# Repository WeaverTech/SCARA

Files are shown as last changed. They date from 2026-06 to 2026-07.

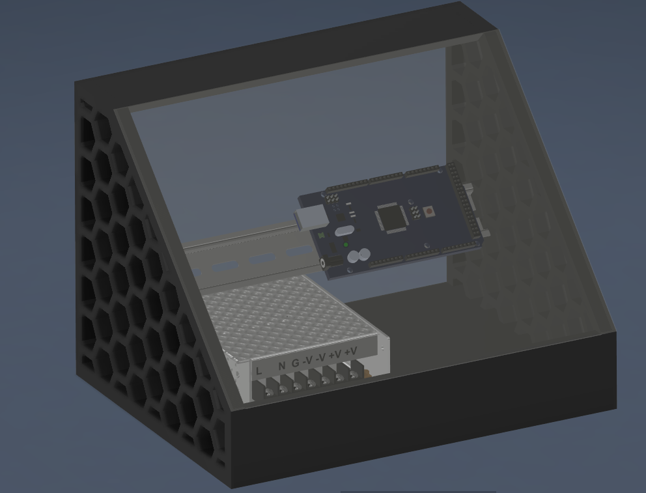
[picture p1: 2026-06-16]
cad/Zrzut ekranu 2026-06-10 202845.png

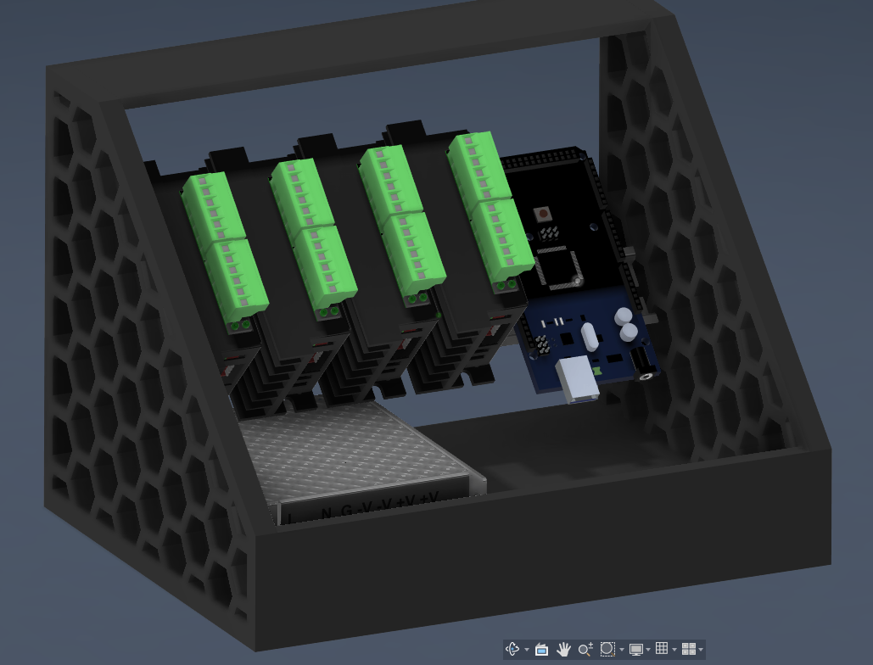
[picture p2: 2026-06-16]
cad/Zrzut ekranu 2026-06-10 203427.png

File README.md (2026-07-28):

# SCARA Robot

Repozytorium robota typu SCARA budowanego z profili aluminiowych 20x20 i
elementow drukowanych w 3D z PET-G. Docelowa konstrukcja to **dwuczlonowe
ramie** (bark + lokiec) z podnoszona osia Z oraz obrotowym efektorem koncowym.

> **Uwaga o prototypie fizycznym:** na etapie testow srodkowy przegub (lokiec)
> moze byc chwilowo pominiety, aby uniknac budowy drugiej przekladni
> cykloidalnej. W repozytorium kod i obliczenia traktuja jednak lokiec jako
> obecny (wersja docelowa). Do pracy bez fizycznego lokcia wystarczy ustawic
> `ELBOW_PRESENT = false` w [`src/main/main.ino`](src/main/main.ino).

## Architektura robota

Lancuch kinematyczny (4 osie / 4 silniki NEMA 17, 4 sterowniki TB6600):

- **Os Z** - ruch gora/dol realizowany na **pasku GT2** (prowadnice na walkach
  8 mm, wsporniki SHF8).
- **Bark (glowna os obrotowa)** - autorska, drukowana w 3D **przekladnia
  cykloidalna 20:1**.
- **Lokiec (srodkowy przegub)** - druga **przekladnia cykloidalna 20:1**
  (w prototypie opcjonalnie pomijana, patrz uwaga powyzej).
- **Efektor koncowy** - obrot narzedzia napedzany **paskiem zebatym** z silnika
  umieszczonego na ramieniu.

## Wymiary i dane kinematyczne

Wymiary zmierzone w CAD (od osi do osi):

| Parametr | Wartosc | Opis |
| --- | ---: | --- |
| Offset osi Z | 165 mm | Odleglosc kolumny Z od osi barku |
| Dlugosc ramienia L1 | 139.928 mm | Bark -> lokiec (zmierzone w CAD) |
| Dlugosc ramienia L2 | 140.000 mm | Lokiec -> efektor (zmierzone w CAD) |
| Maksymalny zasieg | 279.928 mm | L1 + L2 |
| Strefa martwa | 0.072 mm | \|L1 - L2\| |
| Strefa wykluczenia | R = 45 mm | Wokol kolumny Z (ochrona przed kolizja) |
| Przelozenie barku (J1) | 20:1 | Przekladnia cykloidalna |
| Przelozenie lokcia (J2) | 14:1 | Przekladnia cykloidalna |
| Mikrokrok | 1/16 | Ustawienie dla wszystkich sterownikow TB6600 |

### Przeliczniki krokow (mikrokrok 1/16, NEMA 17 = 200 krokow)

Pelny obrot silnika w mikrokrokach: `200 * 16 = 3200`.

```text
J1 (bark,  cykloidalna 20:1): (200 * 16 * 20) / 360 = 177.7778 krokow/stopien
J2 (lokiec, cykloidalna 14:1): (200 * 16 * 14) / 360 = 124.4444 krokow/stopien
Z  (sruba napedowa):           400 krokow/mm
```

Efektor (pasek zebaty z przelozeniem):

```text
steps/deg = (200 * 16 * przelozenie_paska) / 360
przelozenie_paska = zeby_kola_napedzanego / zeby_kola_silnika
```

> Przelozenie paska efektora (`TOOL_BELT_RATIO`) nalezy odczytac z modelu/BOM
> i uzupelnic w `src/main/config.h`.

## Elektronika

| Komponent | Konfiguracja |
| --- | --- |
| Mikrokontroler | Arduino Mega 2560, logika 5 V |
| Sterowniki | 4x TB6600 (wszystkie w uzyciu), sterowanie PUL/DIR/ENA |
| Silniki | 4x NEMA 17 (Z, bark, lokiec, efektor) |
| Zasilanie silnikow | Zasilacz przemyslowy 24 V, 8.3 A, 200 W |
| Zasilanie logiki | Osobny zasilacz 9 V do gniazda Arduino Mega |
| Krancowki | Opto/Hall: J1 -> pin 2, J2 -> pin 3, Z -> pin 18 (przerwania zewnetrzne) |

Masy zasilania logiki i sygnalow sterujacych TB6600 powinny byc wspolne
(mostkowane GND). Zasilanie silnikow (24 V) prowadzone jest oddzielnie do
sterownikow. Efektor nie ma krancowki (pozycja zerowa przyjmowana programowo).

## Modele CAD (`cad/`)

Pliki STEP wyeksportowane z Autodesk Fusion (AP214, jednostki: mm):

- `SCARA.step` - pelny montaz (rama, os Z, ramie, przekladnie, napedy).
- `ramie.step` - sam podzespol ramienia z przekladnia cykloidalna.

Wybrane elementy z listy materialowej (BOM):

- Rama: profile `2020 alu section`, `SCARA_FRAME_V2`.
- Os Z: walki 8 mm, wsporniki `SHF8`, wozek liniowy, pasek GT2.
- Przekladnia cykloidalna `Cycloidal Drive 160mm` (typ TRICY MH-P16): krzywki
  (`cam a-b`, `cam a-c`), pierscienie (`ring a/b/c`), 20 kolkow, waly
  wejsciowy/wyjsciowy, lozyska `NSK 6810ZZ` i `MH-P16`.
- Napedy: `NEMA17` + mocowania, plyty `Axis1`/`Axis2`.

## Struktura repozytorium

```text
.
+-- cad/                  # Modele 3D (STEP) i zrzuty konstrukcji
+-- docs/                 # Schematy, notatki montazowe i kalibracja
+-- host/                 # Klient Pythona (pyserial) dla firmware
+-- sim/                  # Kinematyka (URDF) i symulacja (PyBullet)
+-- webapp/               # Aplikacja webowa: GUI, punkty, programy, symulator
`-- src/
    `-- main/
        +-- config.h      # Geometria, przeliczniki, piny, limity
        `-- main.ino      # Firmware Arduino Mega (IK, homing, protokol)
```

## Aplikacja webowa (teach pendant)

W [`webapp/`](webapp/) znajduje sie lokalna aplikacja webowa w stylu RC+:
jog, pamiec punktow (Teach), edytor programow z interpolacja liniowa,
sterowanie predkoscia i gripperem (serwo SG90), wizualizacja 2D na zywo
oraz wbudowany symulator robota (praca bez sprzetu, port `sim`).
Uruchomienie: `cd webapp && pip install -r requirements.txt &&
uvicorn backend.main:app --port 8000`, GUI pod `http://localhost:8000`.

## Kinematyka i symulacja

W katalogu [`sim/`](sim/) znajduje sie model **URDF** robota, analityczna
kinematyka prosta i odwrotna (`kinematics.py`) oraz symulacja w **PyBullet**
(`simulate.py`). Przeliczniki katow na kroki silnikow sa spojne z firmware.
Model URDF jest standardowy, wiec da sie go uzyc takze w ROS 2 (RViz2, MoveIt 2,
Gazebo). Szczegoly: [`sim/README.md`](sim/README.md).

## Oprogramowanie

Firmware: [`src/main/main.ino`](src/main/main.ino) +
[`src/main/config.h`](src/main/config.h). Zawiera:

- pelna kinematyke odwrotna i prosta w plaszczyznie XY (dwa czlony L1/L2),
- wybor konfiguracji lokcia ("up"/"down") w komendzie ruchu,
- walidacje zasiegu, limitow stawow i strefy wykluczenia wokol kolumny Z,
- 3-fazowy homing (najazd -> odjazd -> wolny latch) na krancowkach z przerwaniami,
- monitoring krancowek w ruchu (przerwania zewnetrzne, ESTOP + wymagany re-home),
- liniowy protokol `OK`/`ERR`/`DONE` dla nadrzednego hosta w Pythonie,
- flage `ELBOW_PRESENT` do pracy bez fizycznego lokcia.

Host Python: [`host/scara_client.py`](host/scara_client.py) (pyserial) -
API `home()`, `move(x, y, z, tool)`, `jog()`, `solve_ik()`, `status()`.
Opis protokolu: [`host/README.md`](host/README.md).

### Wymagania

- Arduino IDE albo Arduino CLI.
- Plytka: **Arduino Mega 2560**.
- Biblioteka: **AccelStepper**.
- Host: Python 3 + **pyserial**.

### Przykladowe komendy szeregowe

Po wgraniu szkicu i otwarciu monitora portu szeregowego (`115200 baud`):

```text
PING
STATUS
HOME
MOVE X200 Y50 Z20 E1
IK X150 Y100
JOG J1 45
JOG Z 10
STOP
ESTOP
```

## Obudowa sterownika (Control Box)

Drukowana w 3D obudowa o strukturze plastra miodu (chlodzenie pasywne + miejsce
na wentylatory). Na dole zasilacz 24 V, nad nim zintegrowana szyna DIN dla
Arduino Mega, a 4 sterowniki TB6600 montowane pionowo obok siebie.

## Status projektu

Geometria (L1, L2, offset Z, zasieg) jest zmierzona w CAD i zweryfikowana.
Przed praca z pelnymi predkosciami nalezy:

1. Zweryfikowac kierunki ruchu wszystkich osi (`HOMING_DIR_*` w `config.h`).
2. Zmierzyc przelozenie paska efektora (`TOOL_BELT_RATIO`).
3. Zweryfikowac pozycje krancowek i wartosci `*_HOME_POS_*` w `config.h`.
4. Sprawdzic stany logiczne czujnikow (`LIMIT_ACTIVE_STATE`) i limity ruchu.

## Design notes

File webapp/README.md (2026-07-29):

# SCARA Web Control

Lokalna aplikacja webowa do sterowania robotem SCARA w stylu teach-pendant
(RC+): jog, pamiec punktow, budowanie i wykonywanie programow, wizualizacja 2D.

Polaczenie z robotem jest **przewodowe** - backend dziala na komputerze
podlaczonym kablem USB do Arduino Mega, a GUI otwierasz w przegladarce pod
`http://localhost:8000`. Wymaga firmware **SCARA-FW 2.2** (`../src/main/`).

## Uruchomienie

### Linux / macOS

```bash
cd webapp
python3 -m venv .venv && source .venv/bin/activate
pip install -r requirements.txt

uvicorn backend.main:app --host 127.0.0.1 --port 8000
```

### Windows (PowerShell)

```powershell
cd webapp
python -m venv .venv
.\.venv\Scripts\Activate.ps1
pip install -r requirements.txt

uvicorn backend.main:app --host 127.0.0.1 --port 8000
```

Nastepnie otworz [http://localhost:8000](http://localhost:8000), wybierz port
(np. `/dev/ttyACM0` lub `COM3`) i kliknij **Polacz**.

> **Praca bez sprzetu:** wybierz port `sim` - wbudowany symulator odpowiada
> identycznym protokolem co firmware i animuje ruch osi w czasie rzeczywistym.

## Polaczenie z Arduino (Windows)

Strona **nie** laczy sie z USB bezposrednio z przegladarki - robi to lokalny
backend (`pyserial`). Jesli wgranie przez Arduino IDE dziala, a **Polacz** na
stronie nie:

1. **Zamknij Serial Monitor** (i najlepiej samo Arduino IDE) - port COM jest
   wyłaczny; zajety port = blad `PORT_BUSY`.
2. Uruchom backend (`uvicorn …`) i otworz `http://127.0.0.1:8000` (nie plik
   `index.html` z dysku).
3. Kliknij **⟳**, wybierz **ten sam COM** co Tools → Port w IDE (nie `sim`).
4. Kliknij **Polacz**. W konsoli na dole powinny pojawic sie linie
   `READY SCARA-FW 2.2` oraz `OK PONG`.
5. Jesli widzisz `NO_RESPONSE`: wgraj ponownie `src/main/` (firmware 2.2),
   baud 115200, bez otwartego monitora szeregowego.

## Funkcje

- **Jog** osiowy (J1/J2/Z/TOOL, wzgledny - dziala tez przed homingiem)
  i kartezjanski (XY przez IK), wybor kroku, konfiguracja lokcia up/down.
- **Homing reczny** (praca bez krancowek): dojedz jogiem do pozycji
  krancowych (J1 = -125 st., J2 = -145 st., Z = 0) i kliknij "SET HOME" -
  biezaca pozycja staje sie pozycja odniesienia (komenda `SETHOME`,
  takze per-os). Uwaga: jog przed homingiem nie ma limitow programowych.
- **Predkosc globalna** 10-100% (suwak, komenda `SPEED`).
- **Gripper** (serwo SG90): otworz/zamknij (komenda `GRIP`).
- **Pamiec punktow**: Teach z biezacej pozycji, Go/Go-liniowy, punkty widoczne
  na wizualizacji; zapis w `data/points.json`.
- **Programy**: lista krokow (ruch joint/liniowy do punktu, Z, TOOL, gripper,
  czekaj) + liczba powtorzen; Run/Pauza/Wznow/Stop z podswietlaniem kroku;
  zapis w `data/programs.json`.
- **Interpolacja liniowa**: trasa TCP dzielona na segmenty 2 mm, cala trasa
  walidowana przed startem (zasieg, limity stawow, strefa kolizji kolumny).
- **Wizualizacja 2D** na zywo: ramie, obszar roboczy, strefa wykluczenia,
  punkty, slad TCP (polling STATUS ~10 Hz przez WebSocket).
- **Bezpieczenstwo**: STOP (rampa) i E-STOP (odciecie sterownikow, wymagany
  ponowny HOME) zawsze widoczne; blokada ruchow przed homingiem.
- **Konsola**: podglad surowej komunikacji + reczne komendy.

## Architektura

```
przegladarka (frontend/)  --HTTP/WS-->  FastAPI (backend/)  --USB-->  Arduino
```

| Modul | Rola |
| --- | --- |
| `backend/main.py` | REST API + WebSocket + serwowanie frontendu |
| `backend/robot_manager.py` | watki: reader / poller STATUS / runner programow |
| `backend/transport.py` | port szeregowy (pyserial) + symulator protokolu |
| `backend/interpolation.py` | segmentacja trasy liniowej + walidacja |
| `backend/kinematics_mm.py` | FK/IK w mm, zgodne 1:1 z firmware |
| `backend/storage.py` | punkty i programy w JSON (`data/`) |
| `frontend/` | GUI: HTML + vanilla JS + canvas |

## Testy

```bash
python3 -m pytest tests/ -q
```

Testy pokrywaja: FK/IK, interpolacje (segmentacja, odrzucanie tras
nieosiagalnych), storage, symulator protokolu oraz pelny cykl programu
(move -> grip -> move liniowy -> grip -> wait) na symulatorze.

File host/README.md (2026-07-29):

# Host Python dla SCARA

Klient `scara_client.py` komunikuje sie z firmware Arduino Mega
(`../src/main/main.ino`) przez port szeregowy (115200 baud).

## Instalacja

```bash
pip install -r requirements.txt
```

## Protokol

Kazda komenda dostaje jedna linie odpowiedzi `OK[ dane]` lub `ERR KOD opis`.
Po zakonczeniu ruchu kontroler wysyla asynchronicznie `DONE`.
Po resecie kontroler wysyla `READY SCARA-FW 2.0`.

| Komenda | Odpowiedz | Opis |
| --- | --- | --- |
| `PING` | `OK PONG` | test lacza |
| `VERSION` | `OK SCARA-FW 2.0` | wersja firmware |
| `STATUS` | `OK STATE=.. HOMED=.. X=.. Y=.. Z=.. J1=.. J2=.. TOOL=..` | pelny stan |
| `HOME [J1\|J2\|Z]` | `OK` / `ERR HOMING_FAIL ...` | homing na krancowkach (bez argumentu: Z, J1, J2) |
| `SETHOME [J1\|J2\|Z\|TOOL] [wart]` | `OK` | homing reczny: biezaca pozycja = krancowa z config.h (lub podana) |
| `JOGR J1\|J2\|Z\|TOOL <delta>` | `OK` + pozniej `DONE` | jog wzgledny; dziala tez przed homingiem (bez limitow!) |
| `MOVE X<mm> Y<mm> [Z<mm>] [T<deg>] [E0\|E1]` | `OK J1=.. J2=..` + pozniej `DONE` | ruch IK (E1 = lokiec "up") |
| `JOG J1\|J2\|Z\|TOOL <wartosc>` | `OK` + pozniej `DONE` | ruch pojedynczej osi |
| `IK X<mm> Y<mm> [E0\|E1]` | `OK J1=.. J2=.. REACHABLE=0\|1` | samo IK, bez ruchu |
| `SPEED <10-100>` | `OK` | globalny procent predkosci osi |
| `GRIP 0\|1` | `OK` | gripper (serwo SG90): 0 = otwarty, 1 = zamkniety |
| `STOP` | `OK` | stop z rampa |
| `ESTOP` | `OK` | stop natychmiastowy + DISABLE (wymaga HOME) |
| `ENABLE` / `DISABLE` | `OK` | sterowniki TB6600 |

Kody bledow: `BAD_CMD`, `NOT_HOMED`, `OUT_OF_REACH`, `EXCLUSION_ZONE`,
`JOINT_LIMIT`, `BUSY`, `LIMIT_HIT`, `HOMING_FAIL`, `AXIS_DISABLED`.

## Przyklad

```python
from scara_client import ScaraClient

with ScaraClient("/dev/ttyACM0") as robot:
    robot.home()                              # Z -> J1 -> J2
    robot.move(x=200.0, y=50.0, z=20.0)       # IK + ruch, czeka na DONE
    print(robot.status())
    print(robot.solve_ik(150.0, 100.0))       # samo IK w firmware
```

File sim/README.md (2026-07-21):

# Kinematyka i symulacja SCARA

Modul opisuje pelna kinematyke robota (model URDF), analityczna kinematyke
prosta/odwrotna oraz symulacje w PyBullet. Wszystko jest spojne ze stalymi
napedu z firmware ([`../src/main/main.ino`](../src/main/main.ino)).

## Zawartosc

| Plik | Opis |
| --- | --- |
| `scara.urdf` | Model URDF (lancuch kinematyczny, limity, geometria). |
| `kinematics.py` | Analityczna FK/IK + mapowanie katow na kroki silnikow. |
| `simulate.py` | Symulacja/wizualizacja w PyBullet (GUI lub headless). |
| `test_kinematics.py` | Testy FK/IK (round-trip, limity, kroki). |
| `requirements.txt` | Zaleznosci Pythona. |

## Model kinematyczny

SCARA z czterema osiami (wszystkie osie obrotowe sa pionowe, +Z):

```
world
  └─(fixed)        base_column        # pionowa wieza z profili 2020
      └─(Z, prismatic)  z_carriage    # podnoszenie na pasku GT2
          └─(shoulder, revolute) link1   # bark,  cykloidalna 20:1
              └─(elbow, revolute)  link2  # lokiec, cykloidalna 20:1
                  └─(tool, revolute) tool_link  # efektor (pasek)
                      └─(fixed) tool_tip         # punkt TCP
```

Parametry (zmierzone w CAD):

| Symbol | Wartosc | Opis |
| --- | ---: | --- |
| `z_offset` | 0.165 m | Kolumna -> os barku |
| `L1` | 0.139928 m | Bark -> lokiec |
| `L2` | 0.140000 m | Lokiec -> efektor |
| zakres Z | 0–0.15 m | Skok osi Z |
| strefa wykluczenia | R = 0.045 m | Wokol kolumny Z |

## Kinematyka prosta (FK)

Pozycja TCP w ukladzie osi barku:

```
x   = L1·cos(θ1) + L2·cos(θ1+θ2)
y   = L1·sin(θ1) + L2·sin(θ1+θ2)
z   = z_carriage                      (oś prismatic, niezależna)
φ   = θ1 + θ2 + θ_tool                (absolutna orientacja narzędzia)
```

## Kinematyka odwrotna (IK)

Dla zadanego (x, y, z, φ):

```
r²       = x² + y²
cos(θ2)  = (r² − L1² − L2²) / (2·L1·L2)
θ2       = ± acos(cos θ2)             (elbow "up" / "down")
θ1       = atan2(y, x) − atan2(L2·sin θ2, L1 + L2·cos θ2)
θ_tool   = φ − (θ1 + θ2)
z        = z (bezpośrednio)
```

Zwraca `None`, gdy punkt jest poza zasiegiem `|L1−L2| ≤ r ≤ L1+L2`.

## Mapowanie na kroki silnikow (spojne z firmware)

```
J1 bark   (cykloidalna 20:1): (200·16·20)/360 = 177.7778 kroków/°
J2 lokiec (cykloidalna 14:1): (200·16·14)/360 = 124.4444 kroków/°
oś Z (śruba napędowa):        400 kroków/mm
efektor (pasek):              (200·16·ratio)/360
```

## Uruchomienie

```bash
cd sim
python3 -m venv .venv && source .venv/bin/activate   # lub virtualenv
pip install -r requirements.txt

# Testy kinematyki
pytest -q

# Demo FK/IK w konsoli
python kinematics.py

# Symulacja bez okna (walidacja URDF + przejazd trajektorii)
python simulate.py --headless --demo

# Symulacja z oknem (wymaga srodowiska graficznego)
python simulate.py --demo
```

> Uwaga: `pybullet` kompiluje sie ze zrodel — na Linuksie wymaga naglowkow
> `python3-dev` oraz kompilatora `g++`/`build-essential`.

## Wykorzystanie w ROS 2 (opcjonalnie)

`scara.urdf` jest standardowym URDF, wiec dziala te z ekosystemem ROS 2:

- wizualizacja: `ros2 launch` + `robot_state_publisher` + RViz2,
- planowanie ruchu: MoveIt 2 (setup assistant wczyta URDF),
- symulacja fizyki: Gazebo (po dodaniu tagow `<gazebo>`).

## Dodanie realnych siatek (mesh) z CAD

Obecnie linki maja geometrie prymitywna (boxy/cylindry) dopasowana wymiarami.
Aby uzyc realnych ksztaltow:

1. W CAD wyeksportuj kazdy czlon do osobnego pliku **STL** (w mm).
2. Umiesc je w `sim/meshes/`.
3. W `scara.urdf` zamien `<geometry><box .../></geometry>` na
   `<geometry><mesh filename="meshes/link1.stl" scale="0.001 0.001 0.001"/></geometry>`
   (skala 0.001, bo URDF jest w metrach, a STL w mm).

## Status / TODO

- [x] Zmierzone realne L1 = 139.928 mm, L2 = 140.000 mm (CAD).
- [ ] Doprecyzowac limity stawow (z renderu widoczne adnotacje 60°/15°/25°).
- [ ] Dodac siatki STL dla lepszej wizualizacji i kolizji.
- [ ] (Opcjonalnie) pakiet ROS 2 + MoveIt 2.

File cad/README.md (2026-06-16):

# CAD

Modele 3D i materialy zrodlowe robota SCARA.

## Pliki w repozytorium

- `SCARA.step` - pelny montaz (rama 2020, os Z, ramie, dwie przekladnie
  cykloidalne, napedy NEMA 17). Eksport z Autodesk Fusion, AP214, jednostki mm.
- `ramie.step` - sam podzespol ramienia z przekladnia cykloidalna.
- `Zrzut ekranu *.png/.jpg` - rendery konstrukcji (cala maszyna, ramie,
  control box).

## Wybrana lista materialowa (BOM)

- **Rama:** profile `2020 alu section`, `SCARA_FRAME_V2`.
- **Os Z:** walki liniowe 8 mm, wsporniki `SHF8`, wozek liniowy
  (`8mm Mil Araba`), nakretka blokujaca, pasek GT2.
- **Przekladnia cykloidalna** `Cycloidal Drive 160mm` (TRICY MH-P16):
  krzywki `cam a-b` / `cam a-c`, pierscienie `ring a/b/c`, 20 kolkow (`pin`),
  waly `input-shaft` / `output shaft`, lozyska `NSK 6810ZZ` i `MH-P16 Bearing`,
  obudowa `housing-top` / `housing-bottom`.
- **Napedy:** `NEMA17 Model` + `Nema 17 mount` + `Gearbox Mount`,
  plyty `Axis1_Plate_*`, `Axis2_Plate_*`, dystanse.
- **Lacznik:** sruby `91292A352`, standoffy.

## Sugerowany podzial przy rozbudowie

- `printed-parts/` - elementy drukowane w 3D z PET-G,
- `control-box/` - obudowa elektroniki i mocowania sterownikow,
- `gearbox/` - przekladnia cykloidalna (bark i lokiec),
- `exports/` - pliki STL/STEP gotowe do druku lub obrobki.

> Pliki STEP sa duze (kilkanascie MB). Przy dalszym przyroscie ciezkich modeli
> warto rozwazyc Git LFS.

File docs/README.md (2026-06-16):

# Dokumentacja

Ten katalog jest przeznaczony na dokumentacje techniczna robota SCARA.

Proponowana zawartosc:

- schemat polaczen Arduino Mega 2560 ze sterownikami TB6600 (4 osie),
- schemat zasilania 24 V dla silnikow i 9 V dla logiki,
- notatki z kalibracji osi Z (pasek GT2) i efektora,
- opis procedury homingu z czujnikami optycznymi (Z, bark, lokiec),
- zdjecia montazu i rewizje mechaniczne.

## Mapa pinow (Arduino Mega 2560 -> TB6600)

| Os | Silnik / naped | STEP (PUL) | DIR | ENA | Krancowka |
| --- | --- | ---: | ---: | ---: | ---: |
| Z | NEMA 17 / pasek GT2 | 22 | 23 | 24 | 40 |
| Bark (SHOULDER) | NEMA 17 / cykloidalna 20:1 | 26 | 27 | 28 | 41 |
| Lokiec (ELBOW) | NEMA 17 / cykloidalna 20:1 | 30 | 31 | 32 | 42 |
| Efektor (TOOL) | NEMA 17 / pasek zebaty | 34 | 35 | 36 | - |

Efektor nie ma krancowki - pozycja zerowa przyjmowana programowo.

## Przeliczniki krokow

Mikrokrok 1/16, NEMA 17 = 200 krokow -> `3200` mikrokrokow na obrot silnika.

| Os | Wzor | Wynik |
| --- | --- | --- |
| Bark | `(200*16*20)/360` | 177.7778 krokow/stopien |
| Lokiec | `(200*16*20)/360` | 177.7778 krokow/stopien |
| Z (GT2) | `3200 / (zeby_kola * 2 mm)` | np. 20T -> 80 krokow/mm |
| Efektor | `(200*16*przelozenie)/360` | zalezne od kol pasowych |

## Dane do uzupelnienia podczas uruchomienia

| Parametr | Stala w kodzie | Wartosc |
| --- | --- | --- |
| Zeby kola pasowego osi Z | `Z_PULLEY_TEETH` | TODO |
| Kroki osi Z na 1 mm | `Z_STEPS_PER_MM` | TODO (wyliczane) |
| Przelozenie paska efektora | `TOOL_BELT_RATIO` | TODO |
| Kroki efektora na 1 stopien | `TOOL_STEPS_PER_DEGREE` | TODO (wyliczane) |
| Dlugosc czlonu L1 (bark->lokiec) | `ARM1_LENGTH_MM` | TODO (pomiar z CAD) |
| Dlugosc czlonu L2 (lokiec->efektor) | `ARM2_LENGTH_MM` | TODO (pomiar z CAD) |
| Stan aktywny krancowki Z | - | TODO |
| Stan aktywny krancowki barku | - | TODO |
| Stan aktywny krancowki lokcia | - | TODO |

## Tryb prototypu bez lokcia

Druga przekladnia cykloidalna moze byc dobudowana pozniej. Do testow bez niej
nalezy w `src/main/main.ino` ustawic:

```cpp
constexpr bool ELBOW_PRESENT = false;
```

Sterownik pominie wtedy zalaczanie, homing i ruchy osi lokcia, zachowujac pelna
obsluge osi Z, barku i efektora.

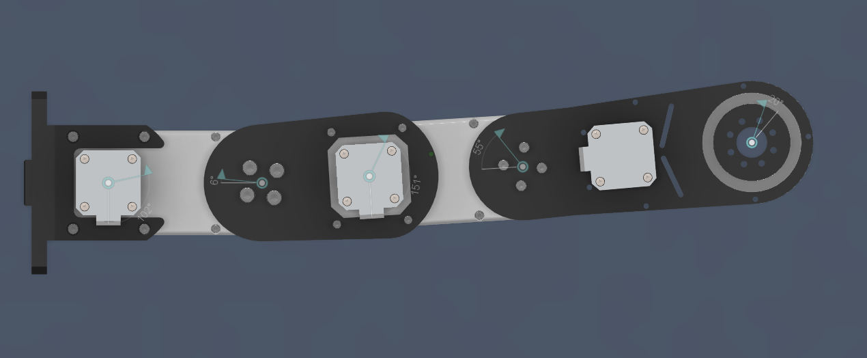
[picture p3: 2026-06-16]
cad/Zrzut ekranu 2026-06-16 174000.png

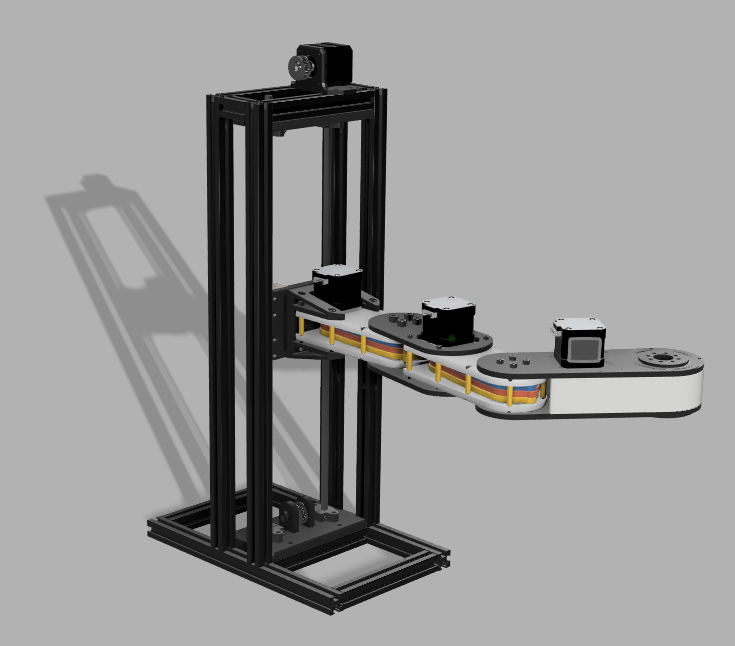
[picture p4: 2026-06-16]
cad/Zrzut ekranu 2026-06-09 221726.png

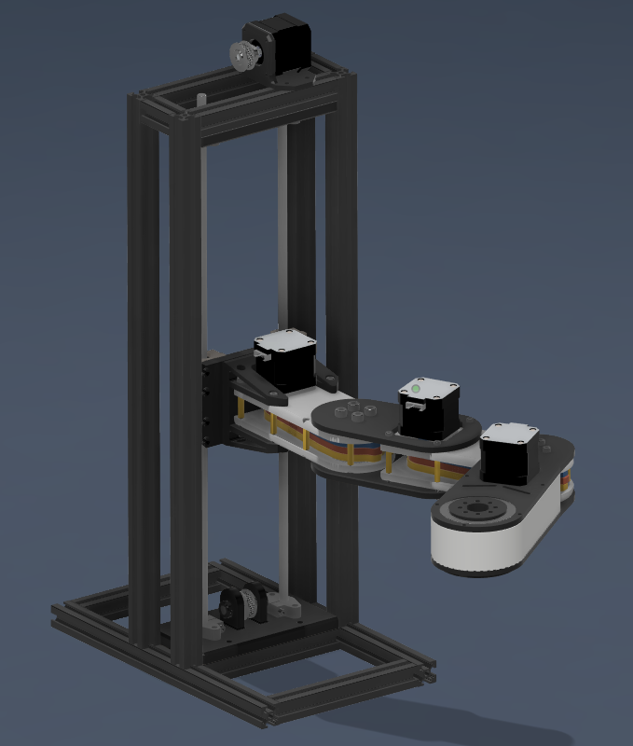
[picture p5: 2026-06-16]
cad/Zrzut ekranu 2026-06-16 173825.png

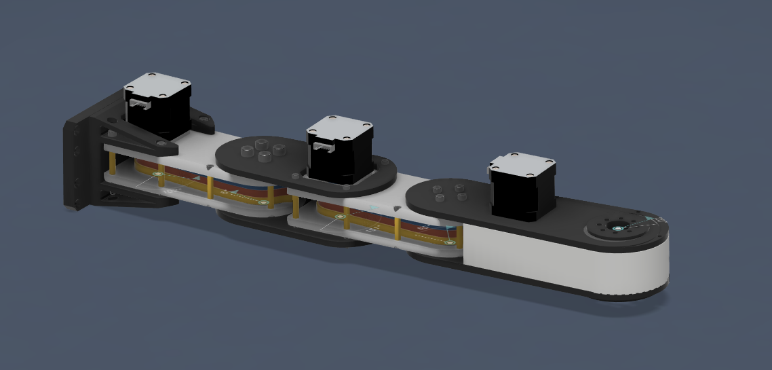
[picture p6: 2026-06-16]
cad/Zrzut ekranu 2026-06-10 000410.png

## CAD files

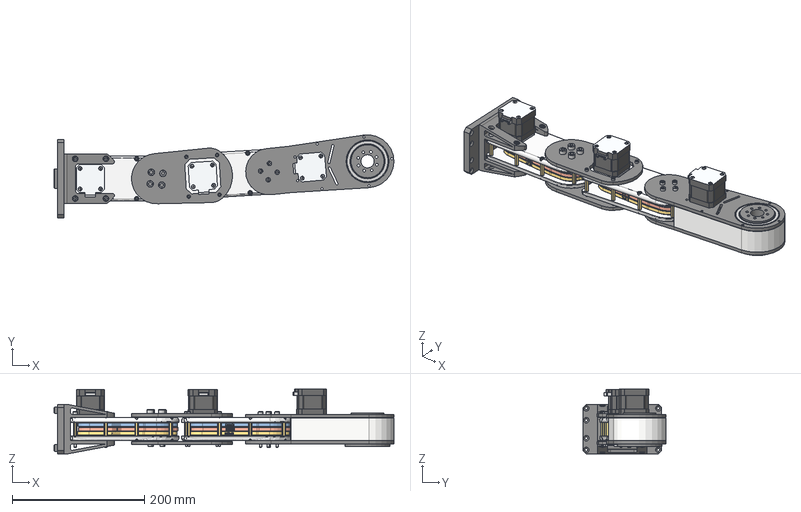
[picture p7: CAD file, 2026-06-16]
cad/ramie.step
513.8 x 125.6 x 98.2 mm
Z axis Plate v2
Komponent33 x 4
MH-P16 Bearing x 4
input bearing x 4
housing-bottom x 2
housing-top x 2
output shaft x 2
output shaft 2 x 2
pin x 40
cam a-b x 2
ring b x 2
cam bearing x 6
ring c x 2
cam a-c x 2
ring a x 2
standoff x 8
standoff_1 x 8
Dystans_Osi x 2
NEMA17 Model x 3
BSHCS ASME B18.3.1M - M3x0.5 x 30 Stal klasy 2 Płaszczyzna x 8
ISO 4032 - M3 Stal 6 Płaszczyzna x 16
BSHCS ASME B18.3.1M - M3x0.5 x 12 Stal klasy 2 Płaszczyzna x 8
BSHCS ASME B18.3.1M - M3x0.5 x 32 Stal klasy 2 Płaszczyzna x 8
BSHCS ASME B18.3.1M - M6x1 x 50 Stal klasy 2 Płaszczyzna x 4
Axis1_Plate_Top
Axis1_Plate_Btm
BSHCS ASME B18.3.1M - M4x0.7 x 50 Stal klasy 2 Płaszczyzna x 8
BSHCS ASME B18.3.1M - M3x0.5 x 50 Stal klasy 2 Płaszczyzna x 4
Gearbox Mount
Axis1_Spacer
Axis1_Spacer(Odbicie)
6810ZZ Outer ring x 2
6810ZZ Shield1 x 2
6810ZZ Inner ring x 2
6810ZZ Ball x 26
6810ZZ Shield2 x 2
Plate_Bottom
GT2 36T id 6.35mm bw 7mm
EndShaft

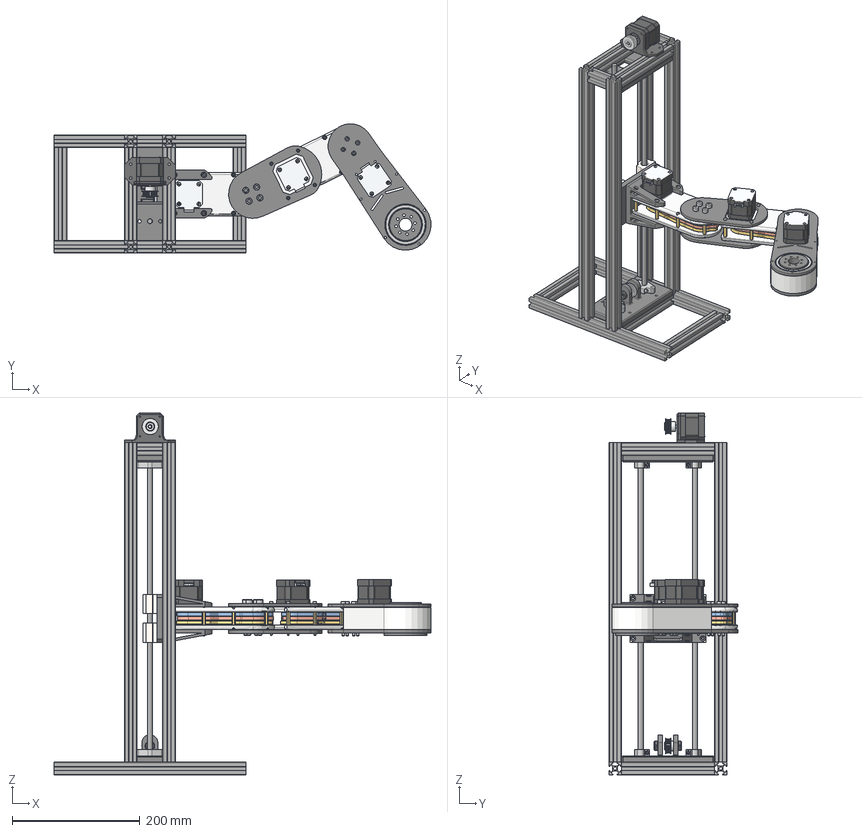
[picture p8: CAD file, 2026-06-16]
cad/SCARA.step
589.6 x 202.5 x 566.2 mm
Konfiguracja 1 v3
Konfiguracja 1 v3 (3)
Konfiguracja 1
Konfiguracja 1 v3 (1)
Konfiguracja 1 v3 (2)
2020 alu section x 2
Konfiguracja 1 v3 (4)
2020 alu section_1 x 6
91292A352
Shaft_Plate
GT2 36T id 6.35mm bw 7mm x 3
8mm Mil Araba - Step x 2
91292A352(Odbicie)
Długość x 2
91292A352(Odbicie) (1)
91292A352(Odbicie)(Odbicie)
NEMA17 Model x 4
Shaft_Plate_Top
8mm Mil Araba - Step_1 x 2
Nema 17 mount
8mm shaft locking nut x 2
Z axis Plate v2
Komponent33 x 4
MH-P16 Bearing x 4
input bearing x 4
housing-bottom x 2
housing-top x 2
output shaft x 2
output shaft 2 x 2
pin x 40
cam a-b x 2
ring b x 2
cam bearing x 6
ring c x 2
cam a-c x 2
ring a x 2
standoff x 8
standoff_1 x 8
Dystans_Osi x 2
BSHCS ASME B18.3.1M - M3x0.5 x 30 Stal klasy 2 Płaszczyzna x 8
ISO 4032 - M3 Stal 6 Płaszczyzna x 16
BSHCS ASME B18.3.1M - M3x0.5 x 12 Stal klasy 2 Płaszczyzna x 8
BSHCS ASME B18.3.1M - M3x0.5 x 32 Stal klasy 2 Płaszczyzna x 8
BSHCS ASME B18.3.1M - M6x1 x 50 Stal klasy 2 Płaszczyzna x 4
Axis1_Plate_Top
Axis1_Plate_Btm
BSHCS ASME B18.3.1M - M4x0.7 x 50 Stal klasy 2 Płaszczyzna x 8
BSHCS ASME B18.3.1M - M3x0.5 x 50 Stal klasy 2 Płaszczyzna x 4
Gearbox Mount
Axis1_Spacer
Axis1_Spacer(Odbicie)
6810ZZ Outer ring x 2
6810ZZ Shield1 x 2
6810ZZ Inner ring x 2
6810ZZ Ball x 26
6810ZZ Shield2 x 2
Plate_Bottom
EndShaft

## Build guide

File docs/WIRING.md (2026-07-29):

# SCARA - kompletny schemat okablowania

Okablowanie dla firmware **SCARA-FW 2.2** (`src/main/config.h`).
Kontroler: Arduino Mega 2560, 4x sterownik TB6600, 4x NEMA 17,
serwo SG90 (gripper), opcjonalnie 3 krancowki optyczne.

## Schemat ogolny

```
                 +--------------------+
 PC (USB) -------|  Arduino Mega 2560 |
                 |  (logika 5 V)      |
 9 V PSU -------(barrel jack)         |
                 +---+----+----+----+-+
                     |    |    |    |         sygnaly PUL/DIR/ENA (5 V)
                +----+    |    |    +-------------------+
                |         |    |                        |
           +----v---+ +---v----+ +--------+        +---v----+
           | TB6600 | | TB6600 | | TB6600 |        | TB6600 |
           |   Z    | |   J1   | |   J2   |        |  TOOL  |
           +--+--+--+ +--+--+--+ +--+--+--+        +--+--+--+
              |  |       |  |       |  |              |  |
            24V  M     24V  M     24V  M            24V  M
              |  |       |  |       |  |              |  |
    24 V PSU -+--|-------+--|-------+--|--------------+  |
    (8.3 A)      |          |          |                 |
              NEMA17     NEMA17     NEMA17            NEMA17
              (os Z)     (bark)     (lokiec)          (efektor)
```

Trzy niezalezne obwody zasilania:

| Obwod | Zrodlo | Zasila |
| --- | --- | --- |
| Silniki | 24 V / 8.3 A (200 W) | Zaciski VCC/GND kazdego TB6600 |
| Logika | 9 V (barrel jack) | Arduino Mega |
| Serwo | 5 V (UBEC/BEC min. 1 A) | SG90 grippera (masa wspolna z Arduino!) |

> TB6600 maja wejscia optoizolowane, wiec masa 24 V **nie musi** byc laczona
> z masa Arduino. Masa serwa SG90 i ewentualnych krancowek **musi** byc
> wspolna z GND Arduino.

## 1. Sterowniki TB6600 -> Arduino Mega

Podlaczenie **wspolna katoda**: wszystkie wejscia `PUL-`, `DIR-`, `ENA-`
kazdego sterownika do **GND Arduino**. Wejscia `+` do pinow:

| Sterownik (os) | PUL+ | DIR+ | ENA+ | PUL-/DIR-/ENA- |
| --- | ---: | ---: | ---: | --- |
| Z (sruba) | 22 | 23 | 24 | GND Arduino |
| J1 (bark, 20:1) | 26 | 27 | 28 | GND Arduino |
| J2 (lokiec, 14:1) | 30 | 31 | 32 | GND Arduino |
| TOOL (efektor) | 34 | 35 | 36 | GND Arduino |

Logika ENA w firmware: pin **LOW = sterownik zalaczony** (ENABLE),
pin HIGH = odlaczony (DISABLE/ESTOP). Przy wspolnej katodzie dziala to
"z pudelka" - nic nie trzeba zmieniac.

## 2. Zasilanie i silniki -> TB6600

Kazdy TB6600:

| Zacisk | Podlaczenie |
| --- | --- |
| VCC | +24 V z zasilacza |
| GND | -V (masa) zasilacza 24 V |
| A+, A- | pierwsza cewka silnika |
| B+, B- | druga cewka silnika |

Pary cewek NEMA 17 znajdziesz multimetrem (para = ok. 1-3 om) albo
zwierajac dwa przewody - jesli walem kreci sie ciezko, to jest para.
Zamiana A+ z A- odwraca kierunek obrotow (alternatywa: `HOMING_DIR_*`
w `config.h`).

**Przekroje:** 24 V do sterownikow oraz silniki min. 0.5 mm2 (AWG20).
Sygnaly logiczne moga byc cienkie (0.25 mm2), najlepiej skrecane parami.

## 3. Przelaczniki DIP na TB6600 (wszystkie 4 sztuki tak samo)

- **Mikrokrok: 1/16 = 3200 imp/obr** - ustaw S1-S3 wg tabelki nadrukowanej
  na sterowniku w pozycji "3200 Pulse/rev" (tabelki roznia sie miedzy
  wersjami TB6600, dlatego kieruj sie nadrukiem, nie internetem).
- **Prad: ok. 1.5 A** (S4-S6 wg nadruku) - typowa wartosc dla NEMA 17;
  sprawdz prad znamionowy swoich silnikow i nie przekraczaj go.

Firmware zaklada 3200 krokow/obrot - inne ustawienie mikrokroku rozjedzie
wszystkie przeliczniki!

## 4. Krancowki (opcjonalne - bez nich uzywaj homingu recznego SETHOME)

Piny z przerwaniami zewnetrznymi, wejscia z `INPUT_PULLUP`,
stan aktywny **LOW**:

| Os | Pin Arduino | Czujnik optyczny (3 piny) | Mikrostyk (2 piny) |
| --- | ---: | --- | --- |
| J1 | 2 | VCC->5V, GND->GND, OUT->pin 2 | COM->GND, NO->pin 2 |
| J2 | 3 | VCC->5V, GND->GND, OUT->pin 3 | COM->GND, NO->pin 3 |
| Z | 18 | VCC->5V, GND->GND, OUT->pin 18 | COM->GND, NO->pin 18 |

Niepodlaczone piny sa bezpieczne (pullup trzyma stan HIGH = nieaktywny),
wiec robot dziala bez krancowek - homing wykonuj komenda `SETHOME`
(sekcja "Homing reczny" w aplikacji webowej).

> Jesli czujnik daje stan HIGH przy zadzialaniu, zmien
> `LIMIT_ACTIVE_STATE` w `config.h` na `HIGH`.

## 5. Gripper - serwo SG90

| Przewod SG90 | Podlaczenie |
| --- | --- |
| Pomaranczowy (sygnal) | pin **44** Arduino |
| Czerwony (+) | +5 V z **osobnego** zrodla 5 V (UBEC/BEC >= 1 A) |
| Brazowy (GND) | GND zrodla 5 V **oraz** GND Arduino (wspolna masa!) |

Nie zasilaj serwa z pinu 5V Arduino - SG90 przy zablokowaniu potrafi
pobrac >0.5 A i zresetuje plytke. Katy otwarcia/zamkniecia: `GRIPPER_OPEN_DEG`
/ `GRIPPER_CLOSED_DEG` w `config.h` (domyslnie 20 / 110 stopni).

## 6. Kolejnosc uruchomienia i test

1. Sprawdz DIP-y (3200 imp/obr, prad) **przed** podaniem 24 V.
2. Podlacz USB (bez 24 V) - wgraj firmware, w monitorze portu (115200)
   sprawdz `PING` -> `OK PONG`.
3. Podaj 24 V, komenda `ENABLE` - silniki powinny "zesztywniec".
4. `SETHOME`, potem `JOGR J1 5` - os ma sie ruszyc o 5 stopni. Sprawdz
   kierunki wszystkich osi (`JOGR J2/Z/TOOL ...`); odwrocone kierunki
   napraw zamiana A+/A- albo znakiem `HOMING_DIR_*`.
5. `GRIP 1` / `GRIP 0` - test grippera.
6. Dalej pracuj z aplikacji webowej (`webapp/`), najpierw na 10-20%
   predkosci.

## Checklist bezpieczenstwa

- [ ] Wspolna masa: Arduino GND <-> PUL-/DIR-/ENA- wszystkich TB6600.
- [ ] Wspolna masa: Arduino GND <-> GND zasilania serwa.
- [ ] Masa 24 V NIE laczona z logika (optoizolacja TB6600).
- [ ] DIP: 3200 imp/obr i prad <= znamionowego silnika (x4).
- [ ] Nigdy nie rozlaczaj przewodow silnika przy wlaczonym 24 V
      (grozi uszkodzeniem sterownika).
- [ ] Pierwsze ruchy: mala predkosc, reka na E-STOP w GUI.

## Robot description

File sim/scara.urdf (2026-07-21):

<?xml version="1.0"?>
<!--
  SCARA robot - model kinematyczny (URDF).

  Lancuch kinematyczny (zgodny z firmware src/main/main.ino):
    world
      +- (fixed)      base_column        # pionowa wieza z profili 2020
            +- (Z, prismatic)  z_carriage   # podnoszenie na pasku GT2
                  +- (shoulder, revolute)  link1   # bark, cykloidalna 20:1
                        +- (elbow, revolute)  link2  # lokiec, cykloidalna 20:1
                              +- (tool, revolute)  tool_link  # efektor (pasek)
                                    +- (fixed)  tool_tip       # punkt TCP

  Jednostki URDF: metry, radiany.
  Wszystkie osie obrotowe sa pionowe (+Z) - typowa geometria SCARA.

  Wymiary (z briefu / CAD; TODO: dlugosci czlonow potwierdzic pomiarem):
    Z offset (kolumna -> os barku)      = 0.165 m
    L1 (os barku  -> os lokcia)         = 0.139928 m  (zmierzone w CAD)
    L2 (os lokcia -> os efektora)       = 0.140000 m  (zmierzone w CAD)
    Skok osi Z (zakres prismatic)       = 0.150 m
-->
<robot name="scara">

  <!-- ===================== Materialy ===================== -->
  <material name="alu">   <color rgba="0.25 0.25 0.27 1.0"/></material>
  <material name="carriage"><color rgba="0.85 0.85 0.88 1.0"/></material>
  <material name="arm">   <color rgba="0.90 0.90 0.92 1.0"/></material>
  <material name="forearm"><color rgba="0.75 0.78 0.82 1.0"/></material>
  <material name="tool">  <color rgba="0.20 0.55 0.90 1.0"/></material>

  <!-- ===================== Baza / kolumna ===================== -->
  <link name="world"/>

  <link name="base_column">
    <visual>
      <origin xyz="0 0 0.30" rpy="0 0 0"/>
      <geometry><box size="0.05 0.20 0.60"/></geometry>
      <material name="alu"/>
    </visual>
    <collision>
      <origin xyz="0 0 0.30" rpy="0 0 0"/>
      <geometry><box size="0.05 0.20 0.60"/></geometry>
    </collision>
    <inertial>
      <origin xyz="0 0 0.30" rpy="0 0 0"/>
      <mass value="3.0"/>
      <inertia ixx="0.1" ixy="0" ixz="0" iyy="0.1" iyz="0" izz="0.02"/>
    </inertial>
  </link>

  <joint name="base_fixed" type="fixed">
    <parent link="world"/>
    <child link="base_column"/>
    <origin xyz="0 0 0" rpy="0 0 0"/>
  </joint>

  <!-- ===================== Os Z (prismatic, pasek GT2) ===================== -->
  <link name="z_carriage">
    <visual>
      <origin xyz="0.04 0 0" rpy="0 0 0"/>
      <geometry><box size="0.10 0.12 0.04"/></geometry>
      <material name="carriage"/>
    </visual>
    <collision>
      <origin xyz="0.04 0 0" rpy="0 0 0"/>
      <geometry><box size="0.10 0.12 0.04"/></geometry>
    </collision>
    <inertial>
      <origin xyz="0.04 0 0" rpy="0 0 0"/>
      <mass value="0.8"/>
      <inertia ixx="0.002" ixy="0" ixz="0" iyy="0.002" iyz="0" izz="0.002"/>
    </inertial>
  </link>

  <joint name="z_lift" type="prismatic">
    <parent link="base_column"/>
    <child link="z_carriage"/>
    <!-- Wozek startuje u dolu zakresu, prowadnice po stronie +X kolumny. -->
    <origin xyz="0.025 0 0.15" rpy="0 0 0"/>
    <axis xyz="0 0 1"/>
    <limit lower="0.0" upper="0.15" effort="50.0" velocity="0.05"/>
  </joint>

  <!-- ===================== Bark (revolute, cykloidalna 20:1) ===================== -->
  <link name="link1">
    <visual>
      <origin xyz="0.069964 0 0" rpy="0 0 0"/>
      <geometry><box size="0.139928 0.05 0.025"/></geometry>
      <material name="arm"/>
    </visual>
    <collision>
      <origin xyz="0.069964 0 0" rpy="0 0 0"/>
      <geometry><box size="0.139928 0.05 0.025"/></geometry>
    </collision>
    <inertial>
      <origin xyz="0.069964 0 0" rpy="0 0 0"/>
      <mass value="0.5"/>
      <inertia ixx="0.001" ixy="0" ixz="0" iyy="0.002" iyz="0" izz="0.002"/>
    </inertial>
  </link>

  <joint name="shoulder" type="revolute">
    <parent link="z_carriage"/>
    <child link="link1"/>
    <!-- Os barku przesunieta o offset osi Z (0.165 m) wzdluz +X od kolumny. -->
    <origin xyz="0.165 0 0.04" rpy="0 0 0"/>
    <axis xyz="0 0 1"/>
    <limit lower="-3.1416" upper="3.1416" effort="20.0" velocity="1.0"/>
  </joint>

  <!-- ===================== Lokiec (revolute, cykloidalna 20:1) ===================== -->
  <link name="link2">
    <visual>
      <origin xyz="0.070 0 0" rpy="0 0 0"/>
      <geometry><box size="0.140 0.045 0.022"/></geometry>
      <material name="forearm"/>
    </visual>
    <collision>
      <origin xyz="0.070 0 0" rpy="0 0 0"/>
      <geometry><box size="0.140 0.045 0.022"/></geometry>
    </collision>
    <inertial>
      <origin xyz="0.070 0 0" rpy="0 0 0"/>
      <mass value="0.35"/>
      <inertia ixx="0.0008" ixy="0" ixz="0" iyy="0.0015" iyz="0" izz="0.0015"/>
    </inertial>
  </link>

  <joint name="elbow" type="revolute">
    <parent link="link1"/>
    <child link="link2"/>
    <!-- L1 = 0.139928 m wzdluz osi czlonu 1 (zmierzone w CAD). -->
    <origin xyz="0.139928 0 -0.025" rpy="0 0 0"/>
    <axis xyz="0 0 1"/>
    <limit lower="-2.6180" upper="2.6180" effort="20.0" velocity="1.0"/>
  </joint>

  <!-- ===================== Efektor (revolute, pasek) ===================== -->
  <link name="tool_link">
    <visual>
      <origin xyz="0 0 -0.02" rpy="0 0 0"/>
      <geometry><cylinder radius="0.02" length="0.04"/></geometry>
      <material name="tool"/>
    </visual>
    <collision>
      <origin xyz="0 0 -0.02" rpy="0 0 0"/>
      <geometry><cylinder radius="0.02" length="0.04"/></geometry>
    </collision>
    <inertial>
      <origin xyz="0 0 -0.02" rpy="0 0 0"/>
      <mass value="0.15"/>
      <inertia ixx="0.0002" ixy="0" ixz="0" iyy="0.0002" iyz="0" izz="0.0002"/>
    </inertial>
  </link>

  <joint name="tool" type="revolute">
    <parent link="link2"/>
    <child link="tool_link"/>
    <!-- L2 = 0.140 m wzdluz osi czlonu 2 (zmierzone w CAD). -->
    <origin xyz="0.140 0 -0.022" rpy="0 0 0"/>
    <axis xyz="0 0 1"/>
    <limit lower="-3.1416" upper="3.1416" effort="10.0" velocity="2.0"/>
  </joint>

  <!-- Punkt TCP (Tool Center Point) - czubek narzedzia. -->
  <link name="tool_tip"/>
  <joint name="tcp_fixed" type="fixed">
    <parent link="tool_link"/>
    <child link="tool_tip"/>
    <origin xyz="0 0 -0.04" rpy="0 0 0"/>
  </joint>

</robot>

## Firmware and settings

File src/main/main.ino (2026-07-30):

#include <AccelStepper.h>
#include <Servo.h>
#include <math.h>

#include "config.h"

// ============================================================================
//  SCARA robot firmware - Arduino Mega 2560 + 4x TB6600 + AccelStepper.
// ----------------------------------------------------------------------------
//  Osie:
//    J1   - bark   (cykloidalna 20:1), krancowka na pinie 2 (INT)
//    J2   - lokiec (cykloidalna 14:1), krancowka na pinie 3 (INT)
//    Z    - sruba napedowa,            krancowka na pinie 18 (INT)
//    TOOL - efektor (pasek GT2), bez krancowki (zero programowe)
//
//  Protokol szeregowy (115200, linie zakonczone '\n') dla hosta Python:
//    Kazda komenda otrzymuje dokladnie jedna linie odpowiedzi:
//      "OK[ dane]"  albo  "ERR <KOD> <opis>"
//    Po zakonczeniu kazdego ruchu kontroler wysyla asynchronicznie "DONE".
//
//  Komendy:
//    PING                        -> OK PONG
//    VERSION                     -> OK SCARA-FW 2.0
//    STATUS                      -> OK STATE=<IDLE|MOVING|HOMING> HOMED=<0|1>
//                                      X=.. Y=.. Z=.. J1=.. J2=.. TOOL=..
//    HOME                        homing wszystkich osi (Z -> J1 -> J2)
//    HOME J1|J2|Z                homing jednej osi
//    SETHOME                     homing reczny: biezaca pozycja wszystkich osi
//                                = pozycje krancowe z config.h (J1/J2/Z) i 0
//                                dla TOOL; osie oznaczane jako "homed"
//    SETHOME J1|J2|Z|TOOL [wart] homing reczny jednej osi; opcjonalna wartosc
//                                nadpisuje domyslna pozycje krancowa
//    JOGR J1|J2|Z|TOOL <delta>   jog WZGLEDNY; dziala takze przed homingiem
//                                (wtedy bez limitow programowych - ostroznie!)
//    MOVE X<f> Y<f> [Z<f>] [T<f>] [E0|E1]   ruch IK do punktu (mm/stopnie);
//                                E0 = lokiec "down", E1 = "up" (domyslnie E1)
//    JOG J1|J2|TOOL <deg>        ruch osi do zadanego kata (bez IK)
//    JOG Z <mm>                  ruch osi Z do zadanej wysokosci
//    IK X<f> Y<f> [E0|E1]        tylko obliczenie IK (bez ruchu) -> OK J1=.. J2=..
//    SPEED <10-100>              globalny procent predkosci wszystkich osi
//    GRIP 0|1                    gripper (serwo SG90): 0 = otwarty, 1 = zamkniety
//    STOP                        zatrzymanie z rampa hamowania
//    ESTOP                       natychmiastowe zatrzymanie + DISABLE
//    ENABLE / DISABLE            zalaczenie / odlaczenie sterownikow
//
//  Kody bledow: BAD_CMD, NOT_HOMED, OUT_OF_REACH, EXCLUSION_ZONE,
//               JOINT_LIMIT, BUSY, LIMIT_HIT, HOMING_FAIL, AXIS_DISABLED
// ============================================================================

AccelStepper axisJ1(AccelStepper::DRIVER, PIN_J1_STEP, PIN_J1_DIR);
AccelStepper axisJ2(AccelStepper::DRIVER, PIN_J2_STEP, PIN_J2_DIR);
AccelStepper axisZ(AccelStepper::DRIVER, PIN_Z_STEP, PIN_Z_DIR);
AccelStepper axisTool(AccelStepper::DRIVER, PIN_TOOL_STEP, PIN_TOOL_DIR);

Servo gripperServo;
bool gripperClosed = false;
uint8_t speedPercent = SPEED_PERCENT_DEFAULT;

enum class State : uint8_t { IDLE, MOVING, HOMING };

State state = State::IDLE;
bool homedJ1 = false;
bool homedJ2 = false;
bool homedZ = false;
bool motionDoneReported = true;

// Flagi ustawiane w ISR krancowek. Poza homingiem trafienie krancowki
// oznacza utrate pozycji -> natychmiastowy stop i wymagany ponowny homing.
volatile bool limitHitJ1 = false;
volatile bool limitHitJ2 = false;
volatile bool limitHitZ = false;
volatile bool limitMonitoringEnabled = false;

char lineBuffer[96];
uint8_t lineLength = 0;

// ---------------------------------------------------------------- ISR
void isrLimitJ1() {
  if (limitMonitoringEnabled) limitHitJ1 = true;
}
void isrLimitJ2() {
  if (limitMonitoringEnabled) limitHitJ2 = true;
}
void isrLimitZ() {
  if (limitMonitoringEnabled) limitHitZ = true;
}

// ------------------------------------------------------------- helpers
bool allHomed() { return homedJ1 && homedZ && (homedJ2 || !ELBOW_PRESENT); }

float scaledSpeed(float base) { return base * (float)speedPercent / 100.0f; }

// Skalowanie predkosci wszystkich osi wg globalnego procentu.
void applySpeedScale() {
  axisJ1.setMaxSpeed(scaledSpeed(J1_MAX_SPEED));
  axisJ2.setMaxSpeed(scaledSpeed(J2_MAX_SPEED));
  axisZ.setMaxSpeed(scaledSpeed(Z_MAX_SPEED));
  axisTool.setMaxSpeed(scaledSpeed(TOOL_MAX_SPEED));
}

bool limitPressed(uint8_t pin) { return digitalRead(pin) == LIMIT_ACTIVE_STATE; }

float j1Degrees() { return axisJ1.currentPosition() / STEPS_PER_DEG_J1; }
float j2Degrees() { return axisJ2.currentPosition() / STEPS_PER_DEG_J2; }
float zMillimeters() { return axisZ.currentPosition() / STEPS_PER_MM_Z; }
float toolDegrees() { return axisTool.currentPosition() / STEPS_PER_DEG_TOOL; }

bool anyAxisMoving() {
  return axisJ1.distanceToGo() != 0 || axisZ.distanceToGo() != 0 ||
         axisTool.distanceToGo() != 0 ||
         (ELBOW_PRESENT && axisJ2.distanceToGo() != 0);
}

void sendOk() { Serial.println(F("OK")); }

void sendErr(const __FlashStringHelper* code, const __FlashStringHelper* msg) {
  Serial.print(F("ERR "));
  Serial.print(code);
  Serial.print(F(" "));
  Serial.println(msg);
}

// --------------------------------------------------------- kinematyka
// Kinematyka prosta: katy stawow [deg] -> pozycja TCP [mm] w ukladzie barku.
void forwardKinematics(float j1Deg, float j2Deg, float& x, float& y) {
  const float t1 = radians(j1Deg);
  const float t12 = radians(j1Deg + j2Deg);
  x = ARM_L1_MM * cosf(t1) + ARM_L2_MM * cosf(t12);
  y = ARM_L1_MM * sinf(t1) + ARM_L2_MM * sinf(t12);
}

// Kinematyka odwrotna: (x, y) [mm] -> katy stawow [deg].
// elbowUp: true -> t2 >= 0 ("up"), false -> t2 <= 0 ("down").
// Zwraca false, gdy punkt jest poza pierscieniem zasiegu.
bool inverseKinematics(float x, float y, bool elbowUp, float& j1Deg, float& j2Deg) {
  const float r2 = x * x + y * y;
  const float r = sqrtf(r2);
  if (r > MAX_REACH_MM + 0.001f || r < MIN_REACH_MM - 0.001f) {
    return false;
  }

  float cosT2 = (r2 - ARM_L1_MM * ARM_L1_MM - ARM_L2_MM * ARM_L2_MM) /
                (2.0f * ARM_L1_MM * ARM_L2_MM);
  cosT2 = constrain(cosT2, -1.0f, 1.0f);
  float t2 = acosf(cosT2);
  if (!elbowUp) t2 = -t2;

  const float t1 = atan2f(y, x) -
                   atan2f(ARM_L2_MM * sinf(t2), ARM_L1_MM + ARM_L2_MM * cosf(t2));

  j1Deg = degrees(t1);
  j2Deg = degrees(t2);
  return true;
}

// Kolumna Z stoi w punkcie (-Z_AXIS_OFFSET_MM, 0) ukladu barku.
// Punkt docelowy nie moze wejsc w strefe wykluczenia wokol kolumny.
bool insideColumnExclusion(float x, float y) {
  const float dx = x + Z_AXIS_OFFSET_MM;
  const float dy = y;
  return (dx * dx + dy * dy) < (Z_COL_EXCLUSION_R * Z_COL_EXCLUSION_R);
}

bool jointsWithinLimits(float j1Deg, float j2Deg) {
  if (j1Deg < J1_MIN_DEG || j1Deg > J1_MAX_DEG) return false;
  if (ELBOW_PRESENT && (j2Deg < J2_MIN_DEG || j2Deg > J2_MAX_DEG)) return false;
  return true;
}

// --------------------------------------------------------------- ruch
void enableAll() {
  axisJ1.enableOutputs();
  axisZ.enableOutputs();
  axisTool.enableOutputs();
  if (ELBOW_PRESENT) axisJ2.enableOutputs();
}

void disableAll() {
  axisJ1.disableOutputs();
  axisJ2.disableOutputs();
  axisZ.disableOutputs();
  axisTool.disableOutputs();
}

void stopAllRamped() {
  axisJ1.stop();
  axisJ2.stop();
  axisZ.stop();
  axisTool.stop();
}

void emergencyStop() {
  // Zerujemy zadane cele w miejscu - bez rampy.
  axisJ1.setCurrentPosition(axisJ1.currentPosition());
  axisJ2.setCurrentPosition(axisJ2.currentPosition());
  axisZ.setCurrentPosition(axisZ.currentPosition());
  axisTool.setCurrentPosition(axisTool.currentPosition());
  disableAll();
  homedJ1 = homedJ2 = homedZ = false;
  state = State::IDLE;
  motionDoneReported = true;
}

void runAllAxes() {
  axisJ1.run();
  axisZ.run();
  axisTool.run();
  if (ELBOW_PRESENT) axisJ2.run();
}

// ------------------------------------------------------------- homing
// Sekwencja: szybki najazd -> odjazd -> wolny najazd (latch) -> zero osi.
bool homeAxisBlocking(AccelStepper& axis, uint8_t limitPin, int8_t dir,
                      long homeSteps, float restoreSpeed) {
  limitMonitoringEnabled = false;  // ISR nie moze przerywac homingu

  const float savedSpeed = restoreSpeed;

  // Faza 1: szybki najazd na krancowke.
  axis.setMaxSpeed(HOMING_SEEK_SPEED);
  axis.move((long)dir * HOMING_MAX_TRAVEL_STEPS);
  while (!limitPressed(limitPin)) {
    if (axis.distanceToGo() == 0) {
      axis.setMaxSpeed(savedSpeed);
      return false;  // przejechano caly zakres bez trafienia
    }
    axis.run();
  }
  axis.stop();
  while (axis.distanceToGo() != 0) axis.run();

  // Faza 2: odjazd od krancowki.
  axis.move((long)(-dir) * HOMING_BACKOFF_STEPS);
  while (axis.distanceToGo() != 0) axis.run();

  // Faza 3: wolny najazd - dokladny latch pozycji.
  axis.setMaxSpeed(HOMING_LATCH_SPEED);
  axis.move((long)dir * (HOMING_BACKOFF_STEPS * 4L));
  while (!limitPressed(limitPin)) {
    if (axis.distanceToGo() == 0) {
      axis.setMaxSpeed(savedSpeed);
      return false;
    }
    axis.run();
  }
  axis.setCurrentPosition(homeSteps);

  // Odjazd na pozycje spoczynkowa tuz za krancowka.
  axis.setMaxSpeed(savedSpeed);
  axis.move((long)(-dir) * HOMING_BACKOFF_STEPS);
  while (axis.distanceToGo() != 0) axis.run();

  limitMonitoringEnabled = true;
  return true;
}

bool homeZ() {
  const bool ok = homeAxisBlocking(
      axisZ, LIMIT_PIN_Z, HOMING_DIR_Z,
      lroundf(Z_HOME_POS_MM * STEPS_PER_MM_Z), scaledSpeed(Z_MAX_SPEED));
  homedZ = ok;
  return ok;
}

bool homeJ1() {
  const bool ok = homeAxisBlocking(
      axisJ1, LIMIT_PIN_J1, HOMING_DIR_J1,
      lroundf(J1_HOME_POS_DEG * STEPS_PER_DEG_J1), scaledSpeed(J1_MAX_SPEED));
  homedJ1 = ok;
  return ok;
}

bool homeJ2() {
  if (!ELBOW_PRESENT) {
    homedJ2 = true;
    axisJ2.setCurrentPosition(0);
    return true;
  }
  const bool ok = homeAxisBlocking(
      axisJ2, LIMIT_PIN_J2, HOMING_DIR_J2,
      lroundf(J2_HOME_POS_DEG * STEPS_PER_DEG_J2), scaledSpeed(J2_MAX_SPEED));
  homedJ2 = ok;
  return ok;
}

// ---------------------------------------------------------- komendy
// Parser argumentow "OS [wartosc]" (np. "J1 -12.5"). Zwraca liczbe pol (0-2).
// Uwaga: avr-libc nie obsluguje "%f" w sscanf (wymaga libscanf_flt), wiec
// sscanf("%7s %f") zawsze zwracal 1 i JOG/JOGR/SETHOME odrzucaly argumenty.
int parseAxisArgs(const char* args, char* axisName, uint8_t nameSize,
                  float& value) {
  while (*args == ' ') ++args;
  uint8_t n = 0;
  while (*args != '\0' && *args != ' ') {
    if (n < nameSize - 1) axisName[n++] = *args;
    ++args;
  }
  axisName[n] = '\0';
  if (n == 0) return 0;
  while (*args == ' ') ++args;
  if (*args == '\0') return 1;
  char* end = nullptr;
  const float parsed = strtod(args, &end);
  if (end == args) return 1;  // po nazwie osi nie ma poprawnej liczby
  value = parsed;
  return 2;
}

// Wyszukuje w komendzie parametr postaci "<litera><liczba>", np. X120.5.
bool parseParam(const char* cmd, char key, float& out) {
  for (const char* p = cmd; *p != '\0'; ++p) {
    if (*p == key && (p == cmd || *(p - 1) == ' ')) {
      out = atof(p + 1);
      return true;
    }
  }
  return false;
}

void printStatus() {
  float x, y;
  forwardKinematics(j1Degrees(), j2Degrees(), x, y);
  Serial.print(F("OK STATE="));
  switch (state) {
    case State::IDLE: Serial.print(F("IDLE")); break;
    case State::MOVING: Serial.print(F("MOVING")); break;
    case State::HOMING: Serial.print(F("HOMING")); break;
  }
  Serial.print(F(" HOMED="));
  Serial.print(allHomed() ? 1 : 0);
  Serial.print(F(" X="));
  Serial.print(x, 3);
  Serial.print(F(" Y="));
  Serial.print(y, 3);
  Serial.print(F(" Z="));
  Serial.print(zMillimeters(), 3);
  Serial.print(F(" J1="));
  Serial.print(j1Degrees(), 3);
  Serial.print(F(" J2="));
  Serial.print(j2Degrees(), 3);
  Serial.print(F(" TOOL="));
  Serial.print(toolDegrees(), 3);
  Serial.print(F(" SPEED="));
  Serial.print(speedPercent);
  Serial.print(F(" GRIP="));
  Serial.println(gripperClosed ? 1 : 0);
}

void commandSpeed(const char* args) {
  const int pct = atoi(args);
  if (pct < SPEED_PERCENT_MIN || pct > SPEED_PERCENT_MAX) {
    sendErr(F("BAD_CMD"), F("uzycie: SPEED <10-100>"));
    return;
  }
  speedPercent = (uint8_t)pct;
  applySpeedScale();
  sendOk();
}

void commandGrip(const char* args) {
  if (args[0] == '0' && args[1] == '\0') {
    gripperClosed = false;
    gripperServo.write(GRIPPER_OPEN_DEG);
  } else if (args[0] == '1' && args[1] == '\0') {
    gripperClosed = true;
    gripperServo.write(GRIPPER_CLOSED_DEG);
  } else {
    sendErr(F("BAD_CMD"), F("uzycie: GRIP 0|1"));
    return;
  }
  sendOk();
}

void commandHome(const char* args) {
  state = State::HOMING;
  bool ok = true;
  if (args[0] == '\0') {
    ok = homeZ() && homeJ1() && homeJ2();  // Z pierwsze - unosi ramie
  } else if (strcmp(args, "Z") == 0) {
    ok = homeZ();
  } else if (strcmp(args, "J1") == 0) {
    ok = homeJ1();
  } else if (strcmp(args, "J2") == 0) {
    ok = homeJ2();
  } else {
    state = State::IDLE;
    sendErr(F("BAD_CMD"), F("uzycie: HOME [J1|J2|Z]"));
    return;
  }
  state = State::IDLE;
  limitMonitoringEnabled = true;
  if (ok) {
    sendOk();
  } else {
    sendErr(F("HOMING_FAIL"), F("krancowka nieosiagnieta w zakresie ruchu"));
  }
}

void commandMove(const char* args) {
  if (!allHomed()) {
    sendErr(F("NOT_HOMED"), F("wykonaj HOME przed ruchem"));
    return;
  }
  float x = NAN, y = NAN, z = NAN, tool = NAN, elbowFlag = 1.0f;
  const bool hasX = parseParam(args, 'X', x);
  const bool hasY = parseParam(args, 'Y', y);
  const bool hasZ = parseParam(args, 'Z', z);
  const bool hasTool = parseParam(args, 'T', tool);
  parseParam(args, 'E', elbowFlag);

  if (!hasX || !hasY) {
    sendErr(F("BAD_CMD"), F("uzycie: MOVE X<mm> Y<mm> [Z<mm>] [T<deg>] [E0|E1]"));
    return;
  }
  if (insideColumnExclusion(x, y)) {
    sendErr(F("EXCLUSION_ZONE"), F("punkt w strefie kolizji z kolumna Z"));
    return;
  }

  float j1, j2;
  if (!inverseKinematics(x, y, elbowFlag >= 0.5f, j1, j2)) {
    sendErr(F("OUT_OF_REACH"), F("punkt poza zasiegiem ramienia"));
    return;
  }
  // Bez fizycznego lokcia osiagalne sa tylko punkty z J2 = 0.
  if (!ELBOW_PRESENT && fabsf(j2) > 0.05f) {
    sendErr(F("OUT_OF_REACH"), F("lokiec wylaczony - punkt nieosiagalny"));
    return;
  }
  if (!jointsWithinLimits(j1, j2)) {
    sendErr(F("JOINT_LIMIT"), F("rozwiazanie IK poza limitami stawow"));
    return;
  }
  if (hasZ && (z < Z_MIN_MM || z > Z_MAX_MM)) {
    sendErr(F("JOINT_LIMIT"), F("Z poza zakresem"));
    return;
  }
  if (hasTool && (tool < TOOL_MIN_DEG || tool > TOOL_MAX_DEG)) {
    sendErr(F("JOINT_LIMIT"), F("TOOL poza zakresem"));
    return;
  }

  axisJ1.moveTo(lroundf(j1 * STEPS_PER_DEG_J1));
  if (ELBOW_PRESENT) axisJ2.moveTo(lroundf(j2 * STEPS_PER_DEG_J2));
  if (hasZ) axisZ.moveTo(lroundf(z * STEPS_PER_MM_Z));
  if (hasTool) axisTool.moveTo(lroundf(tool * STEPS_PER_DEG_TOOL));

  state = State::MOVING;
  motionDoneReported = false;
  Serial.print(F("OK J1="));
  Serial.print(j1, 3);
  Serial.print(F(" J2="));
  Serial.println(j2, 3);
}

void commandJog(const char* args) {
  if (!allHomed()) {
    sendErr(F("NOT_HOMED"), F("wykonaj HOME przed ruchem"));
    return;
  }
  char axisName[8];
  float value = 0.0f;
  if (parseAxisArgs(args, axisName, sizeof(axisName), value) != 2) {
    sendErr(F("BAD_CMD"), F("uzycie: JOG J1|J2|Z|TOOL <wartosc>"));
    return;
  }
  if (strcmp(axisName, "J1") == 0) {
    if (value < J1_MIN_DEG || value > J1_MAX_DEG) {
      sendErr(F("JOINT_LIMIT"), F("J1 poza zakresem"));
      return;
    }
    axisJ1.moveTo(lroundf(value * STEPS_PER_DEG_J1));
  } else if (strcmp(axisName, "J2") == 0) {
    if (!ELBOW_PRESENT) {
      sendErr(F("AXIS_DISABLED"), F("lokiec wylaczony (ELBOW_PRESENT=0)"));
      return;
    }
    if (value < J2_MIN_DEG || value > J2_MAX_DEG) {
      sendErr(F("JOINT_LIMIT"), F("J2 poza zakresem"));
      return;
    }
    axisJ2.moveTo(lroundf(value * STEPS_PER_DEG_J2));
  } else if (strcmp(axisName, "Z") == 0) {
    if (value < Z_MIN_MM || value > Z_MAX_MM) {
      sendErr(F("JOINT_LIMIT"), F("Z poza zakresem"));
      return;
    }
    axisZ.moveTo(lroundf(value * STEPS_PER_MM_Z));
  } else if (strcmp(axisName, "TOOL") == 0) {
    if (value < TOOL_MIN_DEG || value > TOOL_MAX_DEG) {
      sendErr(F("JOINT_LIMIT"), F("TOOL poza zakresem"));
      return;
    }
    axisTool.moveTo(lroundf(value * STEPS_PER_DEG_TOOL));
  } else {
    sendErr(F("BAD_CMD"), F("nieznana os (J1|J2|Z|TOOL)"));
    return;
  }
  state = State::MOVING;
  motionDoneReported = false;
  sendOk();
}

// Jog wzgledny. Dziala rowniez przed homingiem (reczne dojezdzanie do
// pozycji krancowych) - wtedy limity programowe NIE sa egzekwowane,
// bo pozycja osi jest nieznana.
void commandJogRelative(const char* args) {
  char axisName[8];
  float delta = 0.0f;
  if (parseAxisArgs(args, axisName, sizeof(axisName), delta) != 2) {
    sendErr(F("BAD_CMD"), F("uzycie: JOGR J1|J2|Z|TOOL <delta>"));
    return;
  }

  AccelStepper* axis = nullptr;
  float stepsPerUnit = 0.0f;
  bool axisHomed = false;
  float minLimit = 0.0f, maxLimit = 0.0f;

  if (strcmp(axisName, "J1") == 0) {
    axis = &axisJ1; stepsPerUnit = STEPS_PER_DEG_J1; axisHomed = homedJ1;
    minLimit = J1_MIN_DEG; maxLimit = J1_MAX_DEG;
  } else if (strcmp(axisName, "J2") == 0) {
    if (!ELBOW_PRESENT) {
      sendErr(F("AXIS_DISABLED"), F("lokiec wylaczony (ELBOW_PRESENT=0)"));
      return;
    }
    axis = &axisJ2; stepsPerUnit = STEPS_PER_DEG_J2; axisHomed = homedJ2;
    minLimit = J2_MIN_DEG; maxLimit = J2_MAX_DEG;
  } else if (strcmp(axisName, "Z") == 0) {
    axis = &axisZ; stepsPerUnit = STEPS_PER_MM_Z; axisHomed = homedZ;
    minLimit = Z_MIN_MM; maxLimit = Z_MAX_MM;
  } else if (strcmp(axisName, "TOOL") == 0) {
    axis = &axisTool; stepsPerUnit = STEPS_PER_DEG_TOOL; axisHomed = true;
    minLimit = TOOL_MIN_DEG; maxLimit = TOOL_MAX_DEG;
  } else {
    sendErr(F("BAD_CMD"), F("nieznana os (J1|J2|Z|TOOL)"));
    return;
  }

  const long targetSteps = axis->currentPosition() + lroundf(delta * stepsPerUnit);
  if (axisHomed) {
    const float targetUnits = targetSteps / stepsPerUnit;
    if (targetUnits < minLimit || targetUnits > maxLimit) {
      sendErr(F("JOINT_LIMIT"), F("cel poza zakresem osi"));
      return;
    }
  }
  axis->moveTo(targetSteps);
  state = State::MOVING;
  motionDoneReported = false;
  sendOk();
}

// Homing reczny: biezaca fizyczna pozycja osi staje sie pozycja odniesienia.
// Robot nalezy najpierw recznie (JOGR) dojechac do pozycji krancowych.
void commandSetHome(const char* args) {
  char axisName[8] = "";
  float value = NAN;
  const int parsed = parseAxisArgs(args, axisName, sizeof(axisName), value);

  if (parsed <= 0) {
    // SETHOME bez argumentow: wszystkie osie w pozycjach krancowych.
    axisJ1.setCurrentPosition(lroundf(J1_HOME_POS_DEG * STEPS_PER_DEG_J1));
    axisJ2.setCurrentPosition(lroundf(J2_HOME_POS_DEG * STEPS_PER_DEG_J2));
    axisZ.setCurrentPosition(lroundf(Z_HOME_POS_MM * STEPS_PER_MM_Z));
    axisTool.setCurrentPosition(0);
    homedJ1 = homedZ = true;
    homedJ2 = true;
    sendOk();
    return;
  }

  if (strcmp(axisName, "J1") == 0) {
    const float pos = isnan(value) ? J1_HOME_POS_DEG : value;
    axisJ1.setCurrentPosition(lroundf(pos * STEPS_PER_DEG_J1));
    homedJ1 = true;
  } else if (strcmp(axisName, "J2") == 0) {
    const float pos = isnan(value) ? J2_HOME_POS_DEG : value;
    axisJ2.setCurrentPosition(lroundf(pos * STEPS_PER_DEG_J2));
    homedJ2 = true;
  } else if (strcmp(axisName, "Z") == 0) {
    const float pos = isnan(value) ? Z_HOME_POS_MM : value;
    axisZ.setCurrentPosition(lroundf(pos * STEPS_PER_MM_Z));
    homedZ = true;
  } else if (strcmp(axisName, "TOOL") == 0) {
    const float pos = isnan(value) ? 0.0f : value;
    axisTool.setCurrentPosition(lroundf(pos * STEPS_PER_DEG_TOOL));
  } else {
    sendErr(F("BAD_CMD"), F("uzycie: SETHOME [J1|J2|Z|TOOL] [wartosc]"));
    return;
  }
  sendOk();
}

void commandIkOnly(const char* args) {
  float x = NAN, y = NAN, elbowFlag = 1.0f;
  if (!parseParam(args, 'X', x) || !parseParam(args, 'Y', y)) {
    sendErr(F("BAD_CMD"), F("uzycie: IK X<mm> Y<mm> [E0|E1]"));
    return;
  }
  parseParam(args, 'E', elbowFlag);
  float j1, j2;
  if (!inverseKinematics(x, y, elbowFlag >= 0.5f, j1, j2)) {
    sendErr(F("OUT_OF_REACH"), F("punkt poza zasiegiem ramienia"));
    return;
  }
  Serial.print(F("OK J1="));
  Serial.print(j1, 4);
  Serial.print(F(" J2="));
  Serial.print(j2, 4);
  Serial.print(F(" REACHABLE="));
  Serial.println(jointsWithinLimits(j1, j2) && !insideColumnExclusion(x, y) ? 1 : 0);
}
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
void loop() {
  handleSerial();
  runAllAxes();
  checkLimitFlags();

  if (state == State::MOVING && !anyAxisMoving() && !motionDoneReported) {
    state = State::IDLE;
    motionDoneReported = true;
    Serial.println(F("DONE"));
  }
}

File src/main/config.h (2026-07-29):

#ifndef SCARA_CONFIG_H
#define SCARA_CONFIG_H

// ============================================================================
//  SCARA - konfiguracja sprzetowa i geometryczna (Arduino Mega 2560).
//  Wartosci geometryczne zmierzone w CAD - NIE zmieniac bez ponownego pomiaru.
// ============================================================================

// --- GEOMETRIA RAMION SCARA ---
#define ARM_L1_MM 139.928f       // Dlugosc ramienia J1 (Bark -> Lokiec)
#define ARM_L2_MM 140.000f       // Dlugosc ramienia J2 (Lokiec -> Efektor)
#define Z_AXIS_OFFSET_MM 165.0f  // Odleglosc kolumny Z od osi Barku
#define MAX_REACH_MM 279.928f    // Maksymalny zasieg w plaszczyznie XY (L1 + L2)
#define MIN_REACH_MM 0.072f      // Strefa martwa |L1 - L2|
#define Z_COL_EXCLUSION_R 45.0f  // Promien strefy wykluczenia wokol kolumny Z

// --- PRZELICZNIKI KROKOW (TB6600 1/16, NEMA 17 200 kr/obr) ---
#define STEPS_PER_DEG_J1 177.7778f // Przekladnia cykloidalna 20:1 -> (200*16*20)/360
#define STEPS_PER_DEG_J2 124.4444f // Przekladnia cykloidalna 14:1 -> (200*16*14)/360
#define STEPS_PER_MM_Z   400.0f    // Przelicznik dla sruby napedowej osi Z

// Efektor (TOOL) - pasek GT2; przelozenie do weryfikacji na maszynie.
#define TOOL_BELT_RATIO 1.0f
#define STEPS_PER_DEG_TOOL ((200.0f * 16.0f * TOOL_BELT_RATIO) / 360.0f)

// --- PINY KRANCOWEK (HOMING) ---
#define LIMIT_PIN_J1 2   // Opto/Hall krancowka osi 1 (przerwanie zewnetrzne)
#define LIMIT_PIN_J2 3   // Opto/Hall krancowka osi 2 (przerwanie zewnetrzne)
#define LIMIT_PIN_Z  18  // Krancowka osi Z (przerwanie zewnetrzne)

// Stan aktywny krancowek: opto szczelinowe zwykle LOW przy przeslonieciu.
#define LIMIT_ACTIVE_STATE LOW

// --- PINY STEROWNIKOW TB6600 (PUL / DIR / ENA) ---
#define PIN_Z_STEP 22
#define PIN_Z_DIR 23
#define PIN_Z_ENABLE 24

#define PIN_J1_STEP 26
#define PIN_J1_DIR 27
#define PIN_J1_ENABLE 28

#define PIN_J2_STEP 30
#define PIN_J2_DIR 31
#define PIN_J2_ENABLE 32

#define PIN_TOOL_STEP 34
#define PIN_TOOL_DIR 35
#define PIN_TOOL_ENABLE 36

// --- LIMITY PROGRAMOWE OSI (po homingu) ---
#define J1_MIN_DEG -125.0f
#define J1_MAX_DEG 125.0f
#define J2_MIN_DEG -145.0f
#define J2_MAX_DEG 145.0f
#define Z_MIN_MM 0.0f
#define Z_MAX_MM 150.0f
#define TOOL_MIN_DEG -180.0f
#define TOOL_MAX_DEG 180.0f

// --- HOMING ---
// Kierunek najazdu na krancowke (+1 / -1, w krokach silnika).
#define HOMING_DIR_J1 -1
#define HOMING_DIR_J2 -1
#define HOMING_DIR_Z  -1
// Pozycja osi w chwili zadzialania krancowki (ustawiana po homingu).
#define J1_HOME_POS_DEG (J1_MIN_DEG)
#define J2_HOME_POS_DEG (J2_MIN_DEG)
#define Z_HOME_POS_MM   (Z_MIN_MM)
// Predkosci homingu [kroki/s] i odjazd od krancowki [kroki].
#define HOMING_SEEK_SPEED 800.0f
#define HOMING_LATCH_SPEED 150.0f
#define HOMING_BACKOFF_STEPS 800L
#define HOMING_MAX_TRAVEL_STEPS 200000L

// --- DYNAMIKA RUCHU (kroki/s, kroki/s^2) ---
#define J1_MAX_SPEED 4000.0f
#define J1_ACCEL 2000.0f
#define J2_MAX_SPEED 4000.0f
#define J2_ACCEL 2000.0f
#define Z_MAX_SPEED 3000.0f
#define Z_ACCEL 1500.0f
#define TOOL_MAX_SPEED 1200.0f
#define TOOL_ACCEL 600.0f

// --- GRIPPER (serwo modelarskie SG90, sygnal PWM) ---
#define GRIPPER_SERVO_PIN 44
#define GRIPPER_OPEN_DEG 20    // kat serwa: gripper otwarty
#define GRIPPER_CLOSED_DEG 110 // kat serwa: gripper zamkniety

// --- PREDKOSC GLOBALNA ---
#define SPEED_PERCENT_MIN 10
#define SPEED_PERCENT_MAX 100
#define SPEED_PERCENT_DEFAULT 100

// --- KOMUNIKACJA ---
#define SERIAL_BAUD 115200
#define FW_VERSION "SCARA-FW 2.2"

// Prototyp bez drugiej przekladni cykloidalnej: ustaw 0, aby pominac J2.
#define ELBOW_PRESENT 1

#endif  // SCARA_CONFIG_H

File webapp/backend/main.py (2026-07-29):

"""SCARA Web Control - backend FastAPI.

Uruchomienie (z katalogu webapp/):
    uvicorn backend.main:app --host 127.0.0.1 --port 8000

GUI: http://localhost:8000
Polaczenie z robotem jest przewodowe (USB/port szeregowy) - przegladarka
rozmawia z lokalnym backendem, backend z Arduino przez pyserial.
Port "sim" uruchamia wbudowany symulator (praca bez sprzetu).
"""

from __future__ import annotations

import asyncio
from pathlib import Path
from typing import Optional, Set

from fastapi import FastAPI, HTTPException, WebSocket, WebSocketDisconnect
from fastapi.responses import FileResponse
from fastapi.staticfiles import StaticFiles

from . import kinematics_mm as kin
from .models import (ConnectRequest, GripRequest, HomeRequest,
                     JogRelativeRequest, JogRequest, MoveRequest, Point,
                     Program, RawCommandRequest, SetHomeRequest, SpeedRequest)
from .robot_manager import RobotError, RobotManager
from .storage import Storage
from .transport import list_serial_ports

FRONTEND_DIR = Path(__file__).resolve().parent.parent / "frontend"

app = FastAPI(title="SCARA Web Control")
storage = Storage()
manager = RobotManager(storage)

_ws_clients: Set[asyncio.Queue] = set()
_loop: Optional[asyncio.AbstractEventLoop] = None


def _broadcast(event: dict) -> None:
    """Wolane z watkow menedzera - przekazuje zdarzenie do klientow WS."""
    if _loop is None:
        return
    for q in list(_ws_clients):
        _loop.call_soon_threadsafe(q.put_nowait, event)


@app.on_event("startup")
async def _startup() -> None:
    global _loop
    _loop = asyncio.get_running_loop()
    manager.set_event_handler(_broadcast)


@app.on_event("shutdown")
async def _shutdown() -> None:
    if manager.connected:
        manager.disconnect()


def _robot_call(fn, *args, **kwargs):
    try:
        return fn(*args, **kwargs)
    except RobotError as exc:
        raise HTTPException(status_code=409,
                            detail={"code": exc.code, "message": exc.message})
    except TimeoutError as exc:
        raise HTTPException(status_code=504,
                            detail={"code": "TIMEOUT", "message": str(exc)})


# ------------------------------------------------------------- polaczenie
@app.get("/api/ports")
def api_ports():
    return list_serial_ports()


@app.post("/api/connect")
def api_connect(req: ConnectRequest):
    try:
        _robot_call(manager.connect, req.port)
    except HTTPException:
        raise
    except Exception as exc:
        # Ostatnia linia obrony: nie zwracaj gołego 500 bez komunikatu.
        raise HTTPException(
            status_code=500,
            detail={"code": "INTERNAL", "message": str(exc) or exc.__class__.__name__},
        )
    return {"connected": True, "port": req.port}


@app.post("/api/disconnect")
def api_disconnect():
    manager.disconnect()
    return {"connected": False}


@app.get("/api/status")
def api_status():
    return {
        "connected": manager.connected,
        "port": manager.port,
        "program_running": manager.program_running,
        "robot": manager.status(),
    }


# ------------------------------------------------------------------ ruch
@app.post("/api/home")
def api_home(req: HomeRequest):
    _robot_call(manager.home, req.axis)
    return {"ok": True}


@app.post("/api/jog")
def api_jog(req: JogRequest):
    _robot_call(manager.jog, req.axis, req.value)
    return {"ok": True}


@app.post("/api/jog_relative")
def api_jog_relative(req: JogRelativeRequest):
    _robot_call(manager.jog_relative, req.axis, req.delta)
    return {"ok": True}


@app.post("/api/sethome")
def api_sethome(req: SetHomeRequest):
    _robot_call(manager.set_home, req.axis, req.value)
    return {"ok": True}


@app.post("/api/move")
def api_move(req: MoveRequest):
    err = kin.validate_point(req.x, req.y, req.elbow_up)
    if err is not None:
        raise HTTPException(status_code=409,
                            detail={"code": err, "message": "punkt nieosiagalny"})
    if req.linear:
        if manager.program_running:
            raise HTTPException(status_code=409,
                                detail={"code": "PROGRAM_RUNNING",
                                        "message": "zatrzymaj program"})
        # Ruch liniowy jest blokujacy (sekwencja segmentow) - w tle.
        import threading
        threading.Thread(
            target=lambda: _safe_linear(req), daemon=True).start()
        return {"ok": True, "linear": True}
    joints = _robot_call(manager.move_joint, req.x, req.y, z=req.z,
                         tool=req.tool, elbow_up=req.elbow_up)
    return {"ok": True, "joints": joints}


def _safe_linear(req: MoveRequest) -> None:
    try:
        manager.move_linear(req.x, req.y, z=req.z, tool=req.tool,
                            elbow_up=req.elbow_up)
        _broadcast({"type": "linear", "state": "finished"})
    except (RobotError, TimeoutError) as exc:
        _broadcast({"type": "linear", "state": "error", "detail": str(exc)})


@app.post("/api/speed")
def api_speed(req: SpeedRequest):
    _robot_call(manager.set_speed, req.percent)
    return {"ok": True}


@app.post("/api/grip")
def api_grip(req: GripRequest):
    _robot_call(manager.set_grip, req.closed)
    return {"ok": True}


@app.post("/api/stop")
def api_stop():
    manager.stop_program()
    _robot_call(manager.stop_motion)
    return {"ok": True}


@app.post("/api/estop")
def api_estop():
    _robot_call(manager.estop)
    return {"ok": True}


@app.post("/api/command")
def api_command(req: RawCommandRequest):
    reply = _robot_call(manager.command, req.command.strip())
    return {"ok": True, "reply": reply}


@app.get("/api/ik")
def api_ik(x: float, y: float, elbow_up: bool = True):
    ik = kin.inverse(x, y, elbow_up)
    if ik is None:
        return {"reachable": False}
    j1, j2 = ik
    ok = kin.joints_within_limits(j1, j2) and not kin.in_column_exclusion(x, y)
    return {"reachable": ok, "j1": j1, "j2": j2}


# ---------------------------------------------------------------- punkty
@app.get("/api/points")
def api_points():
    return storage.list_points()


@app.post("/api/points")
def api_save_point(point: Point):
    err = kin.validate_point(point.x, point.y, point.elbow_up)
    if err is not None:
        raise HTTPException(status_code=409,
                            detail={"code": err, "message": "punkt nieosiagalny"})
    storage.save_point(point)
    _broadcast({"type": "points_changed"})
    return {"ok": True}
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

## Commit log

2026-06-16 Harden Arduino starter sketch
2026-06-16 Add files via upload
    Główne złożenie
    [SCARA.step]
2026-06-16 Extend to full 4-axis SCARA (add elbow joint, belt-driven Z)
2026-06-16 Add kinematics + URDF model and PyBullet simulation (sim/)
    [scara.urdf]
2026-07-21 Firmware v2: inverse kinematics, interrupt-based homing, Python host protocol
    - src/main/config.h: CAD-measured geometry (L1=139.928, L2=140.000),
    step ratios (J1 20:1 -> 177.7778 st/deg, J2 14:1 -> 124.4444 st/deg,
    Z leadscrew 400 st/mm), limit switch pins 2/3/18, soft limits, homing params
    - src/main/main.ino: full IK/FK, elbow up/down, reach + joint-limit +
    Z-column exclusion-zone validation, 3-phase homing (seek/backoff/latch),
    interrupt limit monitoring with ESTOP, line protocol OK/ERR/DONE for Python
    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
    [scara.urdf]
2026-07-28 Add SCARA Web Control app (teach pendant GUI) + firmware SPEED/GRIP
    Firmware v2.1:
    - SPEED <10-100>: global axis speed percentage (scales AccelStepper maxSpeed)
    - GRIP 0|1: SG90 servo gripper (Servo lib, pin/angles in config.h)
    - STATUS extended with SPEED= and GRIP= fields
    webapp/ (FastAPI + vanilla JS, wired control via local backend):
    - jog panel (joint + cartesian via IK), speed slider, gripper toggle
    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
2026-07-29 Add manual homing (SETHOME) and relative jog (JOGR) for limit-switch-less operation
    Firmware v2.2:
    - JOGR <axis> <delta>: relative jog, allowed BEFORE homing (no soft limits
    while axis position unknown; limits enforced once axis is homed)
    - SETHOME [axis] [value]: current physical position becomes the reference
    (defaults to config.h home positions J1=-125, J2=-145, Z=0, TOOL=0);
    marks axes as homed without needing limit switches
    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
2026-07-29 Add complete wiring guide (docs/WIRING.md): TB6600, motors, PSUs, endstops, SG90
2026-07-29 Fix Arduino serial connect from Web Control (handshake + clear errors)
    The poller used to send STATUS during Mega bootloader reset, racing with
    READY/PING. Open-port failures (busy COM / Serial Monitor) also surfaced as
    opaque 500s. Handshake now waits for READY before starting the poller, serial
    I/O flushes properly, and PORT_BUSY/NO_RESPONSE messages tell the user to
    close the IDE monitor and pick the right COM port.
    [main.py, robot_manager.py, transport.py]
2026-07-29 Fix JOG/JOGR/SETHOME argument parsing on AVR (sscanf %f unsupported)
    [main.ino]
2026-07-30 Retry PING on connect (Mega bootloader can swallow first command after DTR reset)
    [robot_manager.py]
2026-07-30 Do not reconfigure serial port on every read (Windows drivers drop RX buffer)
2026-10-19 Add Z-axis v2 redesign: 3-rod triangle carriage, stiffness analysis, CadQuery model and renders
2026-11-12 Document main as the only SCARA tree and split CAD into v1 and v2
    main held only a title while firmware, the web app, simulation and both
    CAD revisions lived on cursor/* branches that contradicted each other.
    Record which numbers are canonical, which are still unmeasured, and
    which older pinouts must not be revived.
